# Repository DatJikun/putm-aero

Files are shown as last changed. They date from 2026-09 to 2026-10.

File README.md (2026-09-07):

# putm-aero

To jest wiki pakietu aerodynamicznego PUT Motorsport (Formula Student): ustalenia, cele i notatki ze źródeł — bez zgadywania liczb.

**Gdzie jesteśmy.** Jedziemy na aktualnym bolidzie **RWiter017** we Fluencie. Mamy mniej więcej Cx ≈ 1,23, Cz ≈ −3,68 i balans za mocno z przodu (ok. 62%). Chcemy więcej użytecznego docisku przy spokojnym oporze i balansie bliżej pół na pół, pod **Endurance** i **Autocross**. Ruchomego DRS i wentylatora spod podłogi nie robimy.

**Co dalej.** Najpierw **tylnie skrzydło** (trzy elementy na bazie 017), potem **podłoga**, a **przednie** dopiero gdy tył i podłoga ruszają balans. Decyzje na aucie tylko z Fluenta — OpenFOAM 2D jest zaparkowane i nie nadpisuje karty celów.

## Zacznij tutaj

- [Jak ulepszać pakiet](JAK-ULEPSZAC-PAKIET.md) — kolejność prac, dźwignie balansu, czego nie robić.  
- [Kierunek sezonu](SEASON-DIRECTION.md) — skrót H1 → H2 → H3 i otwarte decyzje.  
- [Karta celów](TARGETS.md) — liczby baseline, kill i zakres elementów.  
- [Kampania Fluent H1](SPEC-FLUENT-H1-RWITER017.md) — co kręcić na tylnym skrzydle na aucie.  
- [Workflow](WORKFLOW.md) — jak liczyć i jak trzymać repo, żeby decyzje były uczciwe.  
- [Mapa repo](MAPA-REPO.md) — spis folderów (dodatek; najpierw czytaj powyższe).

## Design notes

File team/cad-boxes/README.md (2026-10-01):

# Boxy aero FS 2027 (+ 2026 do porównania) — STEP do SolidWorksa

Parametryczny generator stref z T 8.2 / T 2.1.3 / T 2.1.4. Reguły i cytaty: [`sources/fs-rules-2027-t8.md`](../../sources/fs-rules-2027-t8.md), szare strefy: [`sources/rules-2027-aero-loopholes.md`](../../sources/rules-2027-aero-loopholes.md).

## Pliki (`out/`)

| Plik | Co to jest | Kiedy otwierać |
|---|---|---|
| `fs2027_dozwolone_full.step` | **tylko** przestrzeń, w której aero może być (keep-outy odjęte, zapas 10 mm) | to jest „box” do pracy |
| `fs2027_dozwolone_half_yneg.step` | to samo, połowa auta (y ≤ 0) — jak CFD | do złożenia CFD |
| `fs2027_zakazane.step` | keep-outy kół T 2.1.3 + dwa warianty T 2.1.4 | do Interference Detection |
| `fs2026_dozwolone_full.step` | boxy 2026 v1.1 | co z obecnego auta wypada w 2027 |
| `ref_opony.step` | opony z parametrów | do dopasowania w złożeniu |
| `limits.md`, `preview.png` | tabela wymiarów, widok z boku i z tyłu | szybki podgląd |

Strefy **dozwolone i zakazane są w osobnych plikach**. SolidWorks nie wczytuje kolorów z STEP-a, więc w jednym pliku nie dałoby się ich odróżnić.

Nazwy brył: `OK_*` dozwolone · `SZARA_*` przód outboard od opon (T 8.2.2 milczy, loophole B3; obcięte do +150 mm) · `KO_*` keep-out dla **każdej** części auta · `Q_*` T 2.1.4 w interpretacji „Tech ustawia dowolnie” (A: 75 mm, B: 250 mm wysokości) · `REF_*` opony.

## Układ współrzędnych

Jak w `PM09-Model-CFD.SLDASM` i w CFD: wymiary w **mm**, **x do tyłu** (0 = oś przednia), **y w bok** (0 = symetria, półauto po y < 0), **z w górę** (0 = grunt). Wstawione do złożenia auta na początek układu wskakują na miejsce (sprawdzone na zrzucie).

## Parametry (`params.toml`) i skąd są

| Parametr | Wartość | Źródło |
|---|---|---|
| Rozstaw osi | 1530 | `solving.jou` + część kolegi |
| Promień opony | 205,75 | `solving.jou` + część kolegi |
| Krawędzie przedniej opony \|y\| | 490 / 700 | część kolegi, po cofnięciu jego zapasu 10 mm (≈) |
| Krawędzie tylnej opony \|y\| | 467,3 / 662 | jw. (≈) |
| x zagłówka (HR) | 1110,75 | jw. (≈) |
| `margin` | 10 | jak u kolegi; `0` = gołe limity regulaminu |
| `width_plane_mode` | `taper` | interpretacja T 8.2.2 b1 — patrz niżej |

Wartości „≈” warto potwierdzić pomiarem w złożeniu. Po zmianie: `python3 gen_boxes.py` (wymaga `pip install cadquery matplotlib`).

## Porównanie z częścią kolegi (`ref-kolegi/REF-REGULATIONS-2027.SLDPRT`)

Wierzchołki obu modeli porównane 1:1 (z jego pliku wyciągnięta geometria Parasolid). Przy tych samych wymiarach, zapasie 10 mm i `width_plane_mode = "parallel"` modele się pokrywają, poza poniższymi różnicami:

| Miejsce | Kolega | Ten generator | Kto ma rację |
|---|---|---|---|
| Przejście przód → środek | x = −290,75 (początek keep-outu koła); między −290,75 a −205,75 box do **401,5 mm** | x = −195,75 (przód opony + zapas); przed nim max **340 mm** | **T 8.2.1 b1:** przed płaszczyzną przez przód opony < 350 mm → u kolegi pas 85 mm jest za wysoki |
| Wąski pas nad tylną oponą | \|y\| ≤ 316,2 | \|y\| ≤ 307,3 | oba legalne; u kolegi zapas tylko ~1 mm (467,3 − 150 = 317,3) |
| Dół / góra przodu | 35,5 / 340,5 | 30 / 340 | do wyjaśnienia, od czego kolega liczył (różnica 0,5–5,5 mm) |
| Wąski pas od wysokości | 421,5 (góra opony + 10) | 401,5 (góra opony − 10) | oba legalne; między 401,5 a 421,5 kolega nie ma żadnej strefy |
| Szerokość nisko za tylną osią | stałe 690 (`parallel`) | zbieżne 690 → 641 (`taper`) | zależy od interpretacji T 8.2.2 b1 → **Q&A** |
| T 2.1.4 | jeden box 510 × 85 na środku | dwa warianty „najgorszy przypadek” w pliku `zakazane` | interpretacja otwarta → **Q&A** |

## Jak sprawdzić auto w SolidWorksie

1. **Keep-out:** Tools → Evaluate → Interference Detection między częściami auta a `fs2027_zakazane.step`. Każda kolizja = problem na Tech.
2. **Envelope aero:** część aero musi się mieścić w sumie brył z `fs2027_dozwolone_*`. Szybki test: Combine → Subtract (część minus bryły `OK_`) — jeśli coś zostaje, to ten fragment wystaje.
3. Najpierw **RWiter017**: pas „góra opony – 700 mm” ma szerokość tylko do \|y\| = 307 mm.

## Uproszczenia

- Opona jako walec (bez cambera, bulge i ugięcia) — przy dużym camberze zostawcie większy zapas (T 8.2.4).
- Środek auta liczony pod **niższą** z gór opon przód/tył (niejasność C2).
- Prześwit 30 mm bez zapasu.

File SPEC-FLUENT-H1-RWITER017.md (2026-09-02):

# Kampania Fluent H1 — tylne skrzydło na RWiter017

Krótki plan Spec po zaparkowaniu 2D OpenFOAM. Liczymy **na aucie we Fluencie**, nie przenosimy Cl z 2D.

**OpenFOAM nie do auta** — porównania i kampania H1 na bolidzie tylko we **Fluencie**. 2D OpenFOAM jest **zaparkowane** (instrukcja na później: `docs/PROTOKOL-2D-OPENFOAM.md`, `SPEC-H1-2D-GATE.md`).

---

## Po co

Cofnąć balans z ok. **62%** na przód w stronę **50/50**, nie pogarszając docisku i trzymając spokojny opór. Najpierw **tylnie skrzydło** (H1), podłoga później (H2).

---

## Punkt startu (nie zmieniać)

Z `TARGETS.md` / RWiter017 @ 15 m/s, half-car, Aref **0,50 m²**, Lref **1,53 m**, moment przy **x = 0,765 m**:

- Cx = **1,229**
- Cz = **−3,682**
- Cm = **−0,429**
- balans przód ≈ **61,6%**

---

## Co kręcić (tylko RW)

Na geometrii **3-elementowej** (domyślna ścieżka):

1. Kąty elementów (zwłaszcza main / flapów) — ostrożnie, bez pchania w stall.  
2. Overlap i szczelina (gap) między elementami.  
3. Ewentualnie lokalne detale TE / endplate tylko jeśli nie mieszają setupu Fluent.

**4 elementy:** jeden case porównawczy obok zwycięskiego 3-el. — nie domyślna baza.

Nie kopiujemy Cl/Cd ani „optimum” z serii 2D OpenFOAM na ten case. 2D może najwyżej podpowiedzieć **kierunek** (np. „nie podnoś main”), gdy wróci z czystym mesh study (`SPEC-H1-2D-GATE.md` = instrukcja na później).

---

## Kill / pass (całe auto)

Case odpada albo nie idzie do CAD final, jeśli:

- |Cz| **spada poniżej 3,682** (gorzej niż baseline), albo  
- Cx **wyraźnie powyżej ~1,23** bez świadomej decyzji, albo  
- balans **nie idzie w stronę 50/50** (albo jedzie w złą stronę — jeszcze bardziej na przód).

Pass diagnostyczny: |Cz| ≥ 3,682, Cx ≲ 1,23, balans bliżej 48–52% niż 62%.

Raportuj Cx, Cz, Cm, balans % (albo Cz przód/tył) przy tym samym Aref/Lref/punkcie momentu.

---

## Kolejność

1. Baseline RWiter017 odtworzony / potwierdzony w Fluent (te same liczby).  
2. Seria 3-el.: overlap → gap → kąty (albo kąty po ustaleniu slotów — byle jeden parametr naraz).  
3. Jeden porównawczy **4-el.**  
4. Dopiero potem H2 podłoga (osobna kampania).

---

## Świadomie poza tą kampanią

- OpenFOAM half-car i 2D OF — **zaparkowane** / nie blokują Fluenta.  
- DRS ruchomy — OUT.  
- Wentylator — OUT.  
- Wąsy — TBD, nie w tej serii.

---

*Źródło prawdy liczb: `TARGETS.md`. Bramka 2D na przyszłość: `SPEC-H1-2D-GATE.md`.*

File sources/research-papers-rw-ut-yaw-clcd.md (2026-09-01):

# Przegląd literatury: tylne skrzydło (3 czy 4 elementy), podłoga w zakręcie, opublikowane liczby docisku i oporu

**Status:** Notatka badawcza do bazy źródeł, stan na 2026-09-01.  
**Język:** Polski, ton koleżeński — pełne zdania, bez telegraficznego skrótu.  
**Zakres:** Publiczne prace, tezy i strony teamów. Preferujemy materiały z EU Formula Student oraz reguł FSG dla EV; inne serie FS/FSAE oznaczamy wprost.  
**Zasada:** Każda liczba w tekście ma link, DOI albo cytat. Jeśli czegoś nie ma w źródle, piszemy **nie znaleziono**. Nic nie wymyślamy.  
**Nasz punkt wyjścia:** konfiguracja RWiter017 (Fluent, Aref zespołu):

- Cx = **1,229**
- Cz = **−3,682**
- Cm = **−0,429**
- balans ≈ **61,6%** na przód (`1/2+Cm/Cz`)

Cel zespołu to mniej więcej pół na pół. Ruchome DRS i wentylator spod podłogi są u nas wyłączone. Rozważamy czteroelementowe tylne skrzydło oraz mocniejszą podłogę.

**Powiązane notatki w bazie:**  
[staniszewski-2023-wing.md](staniszewski-2023-wing.md) · [staniszewski-2024-energy.md](staniszewski-2024-energy.md) · [naglowski-2024-package.md](naglowski-2024-package.md) · [jackson-2018-cfd-drs.md](jackson-2018-cfd-drs.md) · [research-aero-for-targets.md](research-aero-for-targets.md) · [research-balance-shift.md](research-balance-shift.md) · [research-eu-fs-ev-top-teams.md](research-eu-fs-ev-top-teams.md) · [michalecki-fan-ground-effect.md](michalecki-fan-ground-effect.md)

---

## Po ludzku — o co chodziło

Szukaliśmy **otwartych** prac o trzech rzeczach, które nas bolą. Po pierwsze: czy komuś udało się opublikować porównanie **trzech versus czterech elementów** na tylnym skrzydle razem z liczbami. Po drugie: jak **podłoga i dyfuzor** zachowują się przy kącie (skręt / wiatr boczny) oraz w zakręcie i co to robi z balansem. Po trzecie: jakie wartości **Cl, Cd i balansu** leżą w tabelach dla całych pakietów Formula Student.

Wniosek w skrócie brzmi tak. **Trzyelementowe tylne skrzydło jest dobrze udokumentowane**, w tym w naszych notatkach ze Staniszewskiego i Jacksona. **Czteroelementowe skrzydło istnieje w tezach**, ale **nie znaleźliśmy uczciwego porównania head-to-head „3 vs 4 na tym samym aucie” z różnicą współczynników docisku i oporu**. Za to **mapy podłogi przy kącie i w zakręcie** oraz kilka **pełnych pakietów z liczbami** da się zebrać i tu poniżej to robimy.

---

## 1. Tylne skrzydło: trzy czy cztery elementy?

### Co już mamy w bazie (trzy elementy)

Poniższa tabela zbiera to, co już leży w bazie wiedzy o skrzydłach trzyelementowych.

| Twierdzenie | Skąd wiemy | Pewność | Link |
|---|---|---|---|
| PUT RW w Staniszewski 2023 = **3 profile**; 2D izolowane: baseline Fz≈**−398 N**, overlap −30 mm → Fz≈**−565 N** @ 15 m/s; na pojeździe Cx≈**0,72**, Cz≈**−2,03** | tabele pracy | **wysoka** | [staniszewski-2023-wing.md](staniszewski-2023-wing.md) |
| Jackson 2018 (Huddersfield, UK FS): RW **3 el.** E423; gap/overlap wg McBeath; DRS closed CL_DF **1,15**, CD **1,21**; DRS open CL **0,26**, CD **0,79** (−**35%** siły oporu) | abstract + results | **wysoka** | [jackson-2018-cfd-drs.md](jackson-2018-cfd-drs.md); https://www.fieldsjournal.org.uk/article/414/galley/124/download/ |
| Top EU w otwartych źródłach traktują **3-el. RW jako default**; **brak** publicznych liczb „4-el. bije 3 o X%” u AMZ/Aachen/Delft | research-eu-fs-ev-top | **wysoka** (gap) | [research-eu-fs-ev-top-teams.md](research-eu-fs-ev-top-teams.md) |

Innymi słowy: nasze własne źródła i Jackson solidnie opisują układ trzech elementów. Topowe teamy europejskie w publicznych materiałach traktują trzyelementowe RW jako domyślne rozwiązanie. Nigdzie u AMZ, Aachen ani Delft nie znaleźliśmy otwartej liczby w stylu „czwarty element bije trzeci o X procent”.

### Źródła zewnętrzne o 4 elementach / multi-element (liczby tylko wtedy, gdy naprawdę są)

| Twierdzenie | Skąd wiemy | Pewność | Link |
|---|---|---|---|
| **Dynamics UPC** (Quintanas i Yani, 2023, Manresa): w sezonie dodano **czwarty flap** do RW; motywacja = więcej parametrów setupu (kąty + gurney na 3./4. foil); w konkluzji PDF: RW generuje **240 N** docisku, druga konfiguracja flapów obniża opór całego auta o **58 N**, masa RW **7 kg** | abstract + conclusion PDF (UPCommons) | **wysoka** (istnienie 4. foila + N/kg); **średnia** (warunki CFD/V nie w abstractcie — nie porównywać 1:1 z 017) | https://hdl.handle.net/2117/396194 |
| **University of Pretoria** (FSAE, nie EU): za McBeathem zrobiono RW **4-el.** (main E423 + slat + 2 flaps S1223); JavaFoil (inviscid) CL≈**5,7**; Fluent (viscous laminar) CL≈**4,2**; FW Fluent CL≈**3,6** — to **izolowane 2D skrzydło**, nie pełne auto | paper w UP repository | **wysoka** (liczby 2D); **niska** transfer na pakiet PUT | https://repository.up.ac.za/handle/2263/62356 ; bitstream https://repository.up.ac.za/bitstreams/58f0b6ab-1b15-4838-98d1-87fd075c4911/download |
| SV-JME 2016 (SAE Formula): porównanie bazy **2 flaps** vs advanced (**slat + 1 flap**, nie „3 vs 4”): DF **162,4 N → 171,6 N** (~**+6%**) przy tym samym height | DOI | **wysoka** (Δ); **niska** jako 3vs4 | https://doi.org/10.5545/sv-jme.2016.3240 |
| Fluids MDPI 2022 (FS DRS, **3 el.** main 4° / flap1 28° / flap2 60°): 3D z aktuatorami CL≈**1,160**, CD≈**0,397**; DRS → ~**−78%** CD skrzydła — **nie** 4-el. | abstract HTML (pełny HTML MDPI czasem blokowany) | **wysoka** jako 3-el. ref. | https://doi.org/10.3390/fluids7090309 |
| LUT / Metropolia HPF026 (teza, EV FS): parametric study **secondary flaps / slot gaps** + cascade na baseline RW — focus na lap/DF trade-off, **nie** jawne „3 vs 4” z tabelą ΔCl | LUTPUB abstract | **średnia** (kierunek) | https://lutpub.lut.fi/handle/10024/171732 |
| IIUM 2017 (FS downforce package): 2-el. 2D max CL≈**3,63** (L/D 21,5) lub L/D≈**54,1** przy CL≈**2,83**; gurney **0,05·c1** → **+5,8%** DF | DOI | **średnia** (2-el., nie 3vs4) | https://doi.org/10.31436/iiumej.v18i2.679 |

Co z tej tabeli wynika w praktyce. UPC naprawdę dorzuciło czwarty flap w sezonie. W konkluzji PDF podaje:

- docisk RW = **240 N**
- druga konfiguracja flapów → opór całego auta **−58 N**
- masa RW = **7 kg**

Nie mamy jednak w abstractcie pełnych warunków CFD ani prędkości, więc tych niutonów nie wolno porównywać jeden do jednego z naszym `RW_iter017`. Pretoria opisuje czteroelementowe RW według McBeatha, ale to izolowane skrzydło dwuwymiarowe. SV-JME, Fluids MDPI, LUT i IIUM pokazują multi-element, ale żadne z nich nie jest czystym head-to-head „trzy versus cztery elementy na tym samym aucie”.

### Werdykt tematu 1

**Opublikowanego porównania head-to-head trzech versus czterech elementów na tym samym tylnym skrzydle, z różnicą współczynników docisku i oporu/Fz, nie znaleziono.**

Czteroelementowe RW **nie jest „rzadkie jak yeti”** — UPC i Pretoria to robią albo opisują. Nie ma jednak gotowej tabeli w stylu „ile procent zysku daje czwarty element”, którą można wkleić do Specu.

Geometrię startową nadal bierzemy z McBeatha (przez Jacksona):

- gap = **1–4%c**
- overlap = **1–6%c**
- ostatnie flapy wysoko, mniej więcej **25–70°**, tuż przed stalem

---

## 2. Podłoga i dyfuzor — balans przy kącie i w manewrach

### Nasze prace PUT (już w bazie)

| Twierdzenie | Skąd wiemy | Pewność | Link |
|---|---|---|---|
| UT&SW **silnie wrażliwe** na kierunek napływu; przy δ≠0 spadek sił z podłogi; FW/RW „płaskie”; nie ekstrapolować zakrętu z δ=0 | Staniszewski 2024 s. 55–56 | **wysoka** | [staniszewski-2024-energy.md](staniszewski-2024-energy.md) |
| Pełny pakiet (z UT) vs FW&RW: wyższe \|Cz\| w całym δ; Cx krzywe przecinają się ~**10°**; proxy energii toru **F2/F1 = 0,973 → −2,7%** mimo **+~10 kg** UT | wzór (20) + s. 67–68 | **wysoka** (proxy F_ham); **średnia** jako Wh | [staniszewski-2024-energy.md](staniszewski-2024-energy.md) |
| Nagłowski baseline @15 m/s: Fz_ut ≈ **−202 N** z Fz_all ≈ **−561 N** (~**36%**); balans **60,3%** przód | Tab. 5.2–5.3 | **wysoka** (ich model ≠ 017) | [naglowski-2024-package.md](naglowski-2024-package.md) |

Z naszych własnych prac wynika więc, że undertray i sidewalls mocno reagują na kierunek napływu. Przy δ różnym od zera siły z podłogi spadają, a skrzydła zachowują się względnie „płasko”. Nie wolno ekstrapolować zachowania w zakręcie z samego δ = 0. Pełny pakiet z UT daje wyższe \|Cz\| w całym zakresie δ. Z Staniszewskiego 2024:

- krzywe Cx przecinają się około **10°**
- proxy energii toru: **F2/F1 = 0,973** → **−2,7%**
- masa UT ≈ **+10 kg**

U Nagłowskiego (inny model niż `RW_iter017`):

- udział UT ≈ **36%** całego Fz
- balans = **60,3%** na przód

### Chalmers CFS 2021 — tabele: jazda na wprost, zakręt, hamowanie

Źródło: De Wilde et al., *Development and performance evaluation of undertray diffusers during racing manuevers*, Chalmers BSc 2021.  
PDF: https://odr.chalmers.se/bitstreams/2e9b2842-d1d0-4c5a-aa01-a13458f7ddaf/download  

Scenariusz zakrętu w tej pracy (Tab. 3.4):

- R ≈ **12,5 m**
- V ≈ **40 km/h**
- poślizg nadwozia = **3,5°**
- roll = **0,7°**
- kąt skrętu kół ≈ **7,2–7,4°**

Uwaga metrologiczna: w tej pracy CL oznacza **współczynnik docisku** (ujemny lift zapisany jako dodatni CL), a aero balance jest podany **w stronę tyłu**.

**Tabela 4.1 — mały dyfuzor (0 mm start), komponenty:**

| Scenariusz | CD | CL | CL M&D | CL FW | CL RW | Aero balance (tył) |
|---|---:|---:|---:|---:|---:|---:|
| Na wprost | **1,433** | **3,612** | 0,435 | 1,352 | 1,032 | **50,06%** |
| Zakręt | **1,302** | **3,544** | 0,436 | 1,325 | 0,983 | **49,90%** |
| Hamowanie (pitch ~1°) | **1,355** | **2,799** | 0,336 | 0,773 | 1,013 | **67,17%** |

**Kąt ekspansji (start 500 mm) — Tab. 4.3 (fragment):**

| Design | Scenariusz | CD | CL | CL M&D | Balance (tył) |
|---|---|---:|---:|---:|---:|
| **13°** | Na wprost | 1,419 | **3,729** | 0,515 | 49,68% |
| **13°** | Zakręt | 1,380 | **3,603** | 0,470 | 49,38% |
| 15° | Na wprost | 1,424 | 3,640 | 0,483 | 50,36% |
| 19° | Na wprost | 1,402 | 3,663 | 0,497 | 49,35% |

Wniosek autorów brzmi następująco. Kąt **13°** wybrano za odporność w manewrach, a nie dlatego, że zawsze daje maksymalny CL w jednym punkcie. Strakes i side floors dalej pomagają. Typowa literatura startuje od około **15°**; zbyt stromy dyfuzor prowadzi do separacji.

| Twierdzenie | Skąd wiemy | Pewność | Link |
|---|---|---|---|
| Cornering przy R=12,5 m prawie nie zabija CL całego auta vs straight (**3,544 vs 3,612**), ale **braking pitch** zabija FW (−**43%** CL_FW) i cofa balans mocno do tyłu (**67%** tył) | Tab. 4.1 | **wysoka** | Chalmers PDF: https://odr.chalmers.se/bitstreams/2e9b2842-d1d0-4c5a-aa01-a13458f7ddaf/download |
| 13° ekspansji: najwyższy CL w badanych kątach + lepsza kontrola wirów vs 15–19° | Tab. 4.3 + dyskusja | **wysoka** na CFS; **średnia** transfer | Chalmers PDF: https://odr.chalmers.se/bitstreams/2e9b2842-d1d0-4c5a-aa01-a13458f7ddaf/download |

### Oregon State (FSAE undertray) — yaw + roll

| Twierdzenie | Skąd wiemy | Pewność | Link |
|---|---|---|---|
| UT + auto w CFD: nominal ~**50 lb** DF; przy **5° yaw** (bez roll) DF ↑ do **62 lb**; **1° roll** przy yaw obniża DF o **~6%** | § Results | **wysoka** (lb, ich model) | https://ir.library.oregonstate.edu/downloads/7h149t91w |
| Lokalizacja wejścia dyfuzora przesuwa peak podciśnienia → dźwignia **balansu** UT | literatura + design discussion | **wysoka** (kierunek) | https://ir.library.oregonstate.edu/downloads/7h149t91w |

U Oregon State (ich model, lb):

- nominalny DF (UT + auto) ≈ **50 lb**
- przy yaw **5°** (bez roll) DF → **62 lb**
- yaw **5°** + roll **1°** → DF **−~6%**

Lokalizacja wejścia dyfuzora przesuwa peak podciśnienia i działa jak dźwignia balansu undertray.

### FST Lisboa / Técnico — aeromap (EU EV)

| Twierdzenie | Skąd wiemy | Pewność | Link |
|---|---|---|---|
| Na FST10e **yaw** najbardziej wrażliwy: **~16%** zmiany docisku w badanym zakresie; **roll ~9%** DF i **~12%** przesunięcia CoP; ride height **~10%** CD·A i **~20%** −CL·A między peakami; mapa **>100** punktów | abstract tezy | **wysoka** na FST10e; **średnia** transfer | https://scholar.tecnico.ulisboa.pt/records/WjT08GaGU4ee77V1ZI_WgpbeDe_scfAseZd-?lang=en |

Na FST10e yaw okazał się najbardziej wrażliwym kątem. Z abstractu tezy:

- yaw → ~**16%** zmiany docisku w badanym zakresie
- roll → ~**9%** DF i ~**12%** przesunięcia CoP
- ride height → ~**10%** CD·A oraz ~**20%** −CL·A między peakami
- mapa > **100** punktów

### Kirchberger / TU Wien EDGE 14 (EU EV)

| Twierdzenie | Skąd wiemy | Pewność | Link |
|---|---|---|---|
| UT generuje **~40%** docisku EDGE 14 — „most important” device w ich narracji | § Validation | **wysoka** (ich auto) | https://doi.org/10.34726/hss.2023.115880 ; PDF https://repositum.tuwien.at/bitstream/20.500.12708/188917/1/Kirchberger%20Michael%20-%202023%20-%20CFD%20Simulation%20and%20Validation%20of%20a%20Formula%20Student..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 |
| Mesh study (half-car): CLA stagnuje ~**5,1–5,2 m²**, CDA ~**1,7 m²** na najdrobniejszych siatkach; typowy design mesh base 33 mm: CLA **4,72**, CDA **1,57**; converged run CLA **−4,66**, CDA **1,51–1,57** | Tab. 2.1–2.3 | **wysoka** (CLA/CDA = ×A) | https://doi.org/10.34726/hss.2023.115880 ; PDF https://repositum.tuwien.at/bitstream/20.500.12708/188917/1/Kirchberger%20Michael%20-%202023%20-%20CFD%20Simulation%20and%20Validation%20of%20a%20Formula%20Student..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 |

U Kirchbergera undertray generuje około **40%** docisku EDGE 14 i w ich narracji jest „najważniejszym” urządzeniem. Mesh study half-car:

- najdrobniejsze siatki: CLA ≈ **5,1–5,2 m²**, CDA ≈ **1,7 m²**
- typowy design mesh (baza 33 mm): CLA = **4,72**, CDA = **1,57**
- zbieżny run: CLA = **−4,66**, CDA = **1,51–1,57**

### Inne (modelowanie cornering)

| Twierdzenie | Skąd wiemy | Pewność | Link |
|---|---|---|---|
| NTNU (Revolve context): stały yaw ≠ prawdziwy cornering (rotating flow) — efekty momentów bywają **przeciwne** do fixed-yaw | thesis abstract | **wysoka** (metoda) | http://hdl.handle.net/11250/2433712 |
| ASME JEF (Balasko/Zonta, 2025): w corneringu CLA spada **>20%** (mocniej przy małych R); możliwy **rearward** shift balansu / understeer z FW stall | abstract / guest PDF snippet | **med–high** (pełny PDF paywall) | https://doi.org/10.1115/1.4069995 |
| SAE 2017-01-5016 (under tray diffuser FS): best CFD case inlet **3°** / outlet **10°** / GC **30 mm** (L/D); słaby: 5°/16°/50 mm — **paywall abstract**, liczby z abstractu | DOI | **średnia** | https://doi.org/10.4271/2017-01-5016 |

NTNU ostrzega, że stały yaw to nie to samo co prawdziwy cornering z rotating flow — efekty momentów bywają nawet **przeciwne** do fixed-yaw. ASME JEF 2025 raportuje spadek CLA o **więcej niż 20%** w corneringu, mocniejszy przy małych promieniach, oraz możliwy rearward shift balansu albo understeer ze stallu przedniego skrzydła. SAE 2017-01-5016 (liczby z abstractu, pełny tekst za paywallem):

- najlepszy CFD: inlet **3°** / outlet **10°** / GC **30 mm**
- słaby przypadek: **5°** / **16°** / **50 mm**

### Werdykt tematu 2

Mamy **konkretne mapy i tabele** z Chalmers, Oregon, FST Lisboa oraz Staniszewskiego 2024. Wspólny obraz jest jasny. **Undertray to duży udział docisku i największa wrażliwość na yaw oraz attitude.** Braking pitch potrafi bardziej rozwalić balans niż typowy zakręt Formula Student. **Nie wolno zamrażać undertray na samym δ = 0.**

---

## 3. Opublikowane liczby docisku, oporu i balansu dla całych pakietów

> **Uwaga metrologiczna:** Cx/Cz PUT (Fluent, Aref zespołu) nie są tym samym co CLA/CDA w metrach kwadratowych, ani tym samym co Cl/Cd ze stron teamów (często bez Aref albo z DRS). **Nie wolno mieszać tych wielkości w jednym wykresie bez wspólnego Aref.**

| Źródło / kontekst | Cl / Cz / CLA | Cd / Cx / CDA | Balans | Warunki | Link | Conf. |
|---|---|---|---|---|---|---|
| **PUT RWiter017** (kotwica) | Cz **−3,682** | Cx **1,229** | **≈61,6%** przód (`1/2+Cm/Cz`) | 15 m/s, half-car | [research-balance-shift.md](research-balance-shift.md) | **wysoka** |
| **Nagłowski 2024** (PUT, inny model) | Cz **−4,071** | Cx **1,453** | **60,3%** przód | 15 m/s | [naglowski-2024-package.md](naglowski-2024-package.md) | **wysoka** |
| **Staniszewski 2023** 3D pojazd | Cz **−2,036** | Cx **0,726** | nie podano | 15 m/s | [staniszewski-2023-wing.md](staniszewski-2023-wing.md) | **wysoka** |
| **Jackson 2018** + RW DRS closed | CL_DF **1,15** | CD **1,21** | nie (DF głównie tył) | 26,8 m/s; A=1,18 m² | Jackson / Fields | **wysoka** |
| **Jackson** DRS open | CL_DF **0,26** | CD **0,79** | — | A=0,99 m² | [jackson-2018-cfd-drs.md](jackson-2018-cfd-drs.md); https://www.fieldsjournal.org.uk/article/414/galley/124/download/ | **wysoka** |
| **Chalmers CFS** small diffuser straight | CL **3,612** | CD **1,433** | **~50%** tył | 40 km/h | Chalmers PDF Tab. 4.1 | **wysoka** |
| **Chalmers** 13° diffuser straight | CL **3,729** | CD **1,419** | 49,68% tył | 40 km/h | Tab. 4.3 | **wysoka** |
| **Kirchberger EDGE14** | CLA **≈4,66…5,2 m²** | CDA **≈1,51…1,72 m²** | — | half-car StarCCM+; mesh study | reposiTUm DOI | **wysoka** |
| **Rennstall Esslingen** Stallardo25 | CL\*A **4,9** | CD\*A **1,65** | nie znaleziono | cornering **50 km/h** (strona teamu) | https://www.rennstall-esslingen.com/stallardo25 | **wysoka** |
| **PoliTO SC24** Andromeda (EV) | ClA ≈ **4,75** | CdA ≈ **1,45** | nie znaleziono | CFD + WT Dec 2023 (teza Cravero) | https://webthesis.biblio.polito.it/35911/1/tesi.pdf | **wysoka** |
| **eForce CTU.25** (EV, **z DRS**) | Cl **−5,9** | Cd **2,02** | masa 52/48 (nie aero) | DF **320 kg @ 100 km/h**; DRS −**30%** drag | https://eforce.cvut.cz/ctu-25-en/ | **wysoka** (strona); Aref **nie podany** |
| **Wordley & Saunders / Monash 2005** (FSAE WT) | — | CD **0,83** (baseline cytowany przez Jackson) | — | WT | SAE 2006-01-0806/0808 (abstract) | **średnia** (paywall pełny tekst) |
| **AMZ / Aachen / Delft / Tallinn / Joanneum 2024–25** | **nie znaleziono** publicznych Cl/Cd pakietu konkursowego | — | **nie znaleziono** % aero | — | [research-eu-fs-ev-top-teams.md](research-eu-fs-ev-top-teams.md) | **wysoka** (gap) |
| Maryland TR25 active aero (FSAE IC, **nie** EU EV) | CD **1,44 → 0,73** (−49%); CoP **78%→20%** front DF | — | active | AIAA 2026 abstract | https://doi.org/10.2514/6.2026-110799 | **średnia** (inna klasa; DRS-like) |

### MDPI CarMaker Part 2 (ART_X) — mapa Cd versus crosswind + DRS

Źródło: https://www.mdpi.com/2673-4591/79/1/77 (2024) — DRS off/on, kąty ±0…20°.

| Crosswind [°] | CD DRS off | CD DRS on |
|---:|---:|---:|
| 0 | **1,711** | **1,314** (~−25%) |
| ±5 | 1,528 | 1,173 |
| ±10 | 1,367 | 1,045 |
| ±20 | 1,190 | 0,913 |

Ta tabela jest przydatna jako **wzór mapy yaw**, a nie jako target PUT — u nas DRS jest OUT.

---

## Czego uczciwie nie znaleziono

Poniżej wypisujemy uczciwie to, czego nie znaleźliśmy albo czego nie wolno przeskalować na nasz pakiet.

1. **Brak publikacji Δ(3-el → 4-el) na tym samym RW** z Cl/Cd/Fz i wspólnym Aref. Hipoteza H1 zostaje więc **hipotezą CAD/CFD**, a nie twierdzeniem typu „literatura mówi +X%”.
2. Topowe teamy EU (AMZ, Aachen, Delft, Tallinn, Joanneum) **nie publikują** Cl/Cd ani balansu konkursowego. Mamy tylko procesy oraz rzadkie CLA/CDA (Esslingen, Kirchberger, PoliTO, CTU).
3. W Staniszewskim 2024 **konkretne Cx(δ)/Cz(δ) są tylko na wykresach**. W plain text brak tabeli punktowej — nie OCR-owano wykresów.
4. ASME cornering 2025: pełny PDF stoi za paywallem. Mamy snippet o spadku CLA **>20%**, ale nie pełną tabelę.
5. U Quintanasa (conclusion PDF, UPCommons):

   - docisk RW = **240 N**
   - Δopór auta = **58 N**
   - masa RW = **7 kg**

   **Prędkość, Aref oraz to, czy pomiar dotyczy izolowanego RW czy full-car, nie zostały wyciągnięte w tej sesji z pełnego tekstu.** Nie wolno więc skalować tych wartości na `RW_iter017`.
6. CTU.25 podaje Cl/Cd **z DRS w pakiecie**. U nas DRS jest OUT. Traktujemy te liczby jako górny rząd wielkości DF, a nie jako setup do kopiowania.
7. Fan oraz powered ground effect leżą poza zakresem Specu (OUT). Szczegóły są w notatce Michalecki w KB.

---

## Co z tego wynika dla naszego zespołu

**H1 — kandydat na RW 4-elementowe.** Literatura **nie da Ci gotowego ΔCl**. Daje motywację: UPC podkreśla więcej parametrów setupu oraz ekspozycję ostatniego flapu; Pretoria i McBeath pokazują, że układ 4-elementowy jest osiągalny w boxie FSAE. Ostrzeżenia: Staniszewski przypomina, że 2D nie równa się 3D coupling; UPC waży RW około **7 kg**; trzeba pilnować sztywności według T8.3. Gate dla nas — tabela na pakiecie 017 z Δbalans / ΔCx / ΔCz względem baseline 3-elementowego:

- Cx ≲ **1,23**
- \|Cz\| ≥ **3,682**

**H2 — undertray.** To jest **najmocniej udokumentowana** dźwignia w tym researchu. Z paperów:

- Chalmers: kąt **13°** + strakes + manewry
- Oregon: yaw **5°**; roll przy yaw → DF **−~6%**
- FST Lisboa: ~**16%** zmiany DF od yaw
- Staniszewski 2024: mapy δ; proxy energii **−2,7%**
- Kirchberger: UT ≈ **40%** DF

Szukamy więc **tylniejszego** docisku dyfuzora **bez** dokręcania nosa przedniego skrzydła. Bramka decyzyjna: mapa Cx/Cz versus δ (plus roll/ride height, jeśli starczy budżetu) przed zamrożeniem geometrii.

**Balans 61,6% → około 50%.** Żaden top team nie opublikował instrukcji „róbcie 50% tak jak my”. Chalmers celuje w okolice **50/50** (nawet z narracją rear-biased). Nasze dźwignie to **H1 RW + H2 UT**, potem ewentualnie odciążenie FW (H3), a wąsy zostają TBD (H4). Nie dokręcamy samego przedniego skrzydła.

**DRS OUT / fan OUT.** Jackson oraz MDPI/CTU pokazują, że otwarty DRS zjada docisk. U nas w 019/020:

- \|Cz\| ≈ **3,01**
- to poniżej kotwicy **3,682**

Fan jest opisany u Michaleckiego. Nie projektujemy peak-DF przez te ścieżki.

**Kolejność pracy:** H1 → H2 → (H3) → H4. Zawsze na **pełnym pakiecie** oraz przynajmniej z **mapą versus δ**.

---

## Lista źródeł

| # | Źródło | Temat | Liczby? |
|---|---|---|---|
| 1 | Staniszewski 2023 (PUT) | RW 3-el. | tak |
| 2 | Staniszewski 2024 (PUT) | yaw/δ, UT | tak (proxy) |
| 3 | Nagłowski 2024 (PUT) | pakiet Fz/balans | tak |
| 4 | Jackson 2018 | RW 3-el. + DRS | tak |
| 5 | Quintanas UPC 2023 | RW **4-el.** | tak (N, kg) |
| 6 | Pretoria FSAE paper | RW 4-el. 2D CL | tak |
| 7 | Chalmers undertray 2021 | UT manewry | tak (tabele) |
| 8 | Oregon State undertray | yaw/roll UT | tak |
| 9 | FST Lisboa aeromap abstract | yaw sensitivity | tak (%) |
| 10 | Kirchberger 2023 EDGE14 | CLA/CDA, UT% | tak |
| 11 | PoliTO Cravero 2025 | ClA/CdA SC24 | tak |
| 12 | eForce CTU.25 page | Cl/Cd + DF kg | tak |
| 13 | Esslingen Stallardo25 | CL\*A/CD\*A | tak |
| 14 | MDPI Eng. Proc. 79/77 | Cd vs yaw + DRS | tak |
| 15 | SV-JME 2016 | multi-el. ΔDF | tak |
| 16 | Fluids 2022 DRS 3-el. | CL/CD skrzydła | tak |
| 17 | IIUM 2017 | 2-el. CL | tak |
| 18 | NTNU cornering CFD thesis | metoda yaw vs rotate | qualitative+ |
| 19 | ASME JEF 2025 cornering | CLA −>20% | tak (snippet) |
| 20 | LUTPUB Metropolia RW study | parametric flaps | abstract |
| 21 | research-eu-fs-ev-top (KB) | top EU gaps | meta |

**Liczba źródeł z liczbami (Cl/Cd/Fz/CLA/%/N):** **≥ 16** (wiersze 1–16 powyżej plus snippet ASME).  
**Źródła bez head-to-head 3 vs 4:** ta luka jest jawna i pozostaje otwarta.

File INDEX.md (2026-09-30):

# FS Aero — baza wiedzy (indeks)

Stan na 2026-09-01 (aktualizacje nocne do 2026-09-02).
Tu trzymamy źródła i zamrożone ustalenia zespołu.
Liczby tylko ze źródeł — bez zgadywania.

---

## Nawigacja

- [WORKFLOW.md](WORKFLOW.md) — co poprawić w workflow CFD i repo
- [JAK-ULEPSZAC-PAKIET.md](JAK-ULEPSZAC-PAKIET.md) — jak ulepszać pakiet (wiki)
- [MAPA-REPO.md](MAPA-REPO.md) — mapa repozytorium (co w każdym folderze, czego gdzie szukać)

## Ustalenia zamrożone (zespół)

**Punkt odniesienia (baseline):** `RW_iter017` to **aktualny bolid** po zawodach.

- Osoba w arkuszu: Michał Narożny, status Done, data 27.12.2025.
- Cx = **1,229**
- Cz = **−3,682**
- Cm = **−0,429**
- efektywność ≈ **2,996**
- Źródło: [sources/team-rwiter017-baseline.md](sources/team-rwiter017-baseline.md) oraz CSV `team/rw-iters-2025-2026.csv`.
- Wariant `RW_iter017.2` służy tylko do kontroli rozbieżności skryptu Fluent. **Nie** zamienia kotwicy.
- `Baseline002` to historyczny miks (FWiter011 + RWiter017 + UTiter002). To **nie** jest kotwica.

**Cel projektowy (lead):** jak największy docisk przy balansie około **50/50** (roboczo **48–52%** na przód).
Przy tym samym docisku nie pogarszamy oporu względem baseline (orientacyjnie Cx ≲ **1,23**).
Prędkość odniesienia w pracach PUT i w setupie CFD: **15 m/s**.

**Zakres elementów (na start):**

- Skrzydło tylne, przednie, podłoga i sekcje boczne — **wchodzą**.
- Tylne skrzydło: rozważamy **4 elementy** jako kandydata względem obecnych 3.
- Wąsy (profil typu S1223) — **jeszcze nie wiadomo**; dobór profilu dopiero pod miejsce na aucie.
- Wentylator spod podłogi — **nie**.
- DRS ruchomy — **nie**; ewentualnie tylko układ **pasywny** (jak testy 019/020), poza ścieżką peak-docisku.
- Model turbulencji Fluent: **Realizable k-ε + Enhanced Wall Treatment**.
  OpenFOAM: to samo albo wall functions przy y+ > 30 (maszyna 16 GB).

**Priorytet eventów:** Endurance i Autocross.
Cel: maksymalny docisk przy możliwie niskim oporze.
Balans: z ok. **61,6%** na przód w stronę ok. **50/50** (ok. **12 punktów procentowych**).

**Potwierdzone:** wiersz `Baseline_1` z arkusza podłogi **nie jest** tym samym bolidem co `RW_iter017`.
RWiter017 = aktualny bolid po zawodach.
Liczb balansu ok. 69% z Baseline_1 nie używamy jako startu.

**Balans RWiter017:** ≈ **61,6%** na przód (z Cm/Cz arkusza; decyzja: „jak w arkuszu”).
Do ok. 50/50 brakuje ok. **12 pp** — cofamy docisk (tylnie skrzydło / podłoga), nie dokręcamy samego przodu.
Postprocessing z OneDrive to JPG bez CSV sił, więc kotwica z arkusza zostaje.

**Aref:**

- half-car ≈ **0,50 m²** (w simach bywa 0,49–0,51)
- pełny bolid ≈ **1,0 m²**

**Otwarte:**

- masa bolidu i budżet energii,
- wąsy — ostateczny dobór profilu.

Łańcuch iteracji przedniego skrzydła (`team/fw-iters-2025-2026.csv`) to kontekst rozwoju FW.
To **nie** jest baseline całego bolidu.

---

## Literatura (prace dyplomowe / paper)

| # | Plik | Krótko |
|---|---|---|
| 1 | [sources/staniszewski-2023-wing.md](sources/staniszewski-2023-wing.md) | Staniszewski 2023 — optymalizacja 3-elementowego skrzydła tylnego (2D/3D, 15 m/s). Na pojeździe Cx/Cz ≈ 0,72 / −2,03 (inny pakiet niż dzisiejszy baseline). |
| 2 | [sources/staniszewski-2024-energy.md](sources/staniszewski-2024-energy.md) | Staniszewski 2024 — mapy Cx/Cz vs kąt skrętu i proxy energii; podłoga pomaga mimo +~10 kg. |
| 3 | [sources/naglowski-2024-package.md](sources/naglowski-2024-package.md) | Nagłowski 2024 — wąsy S1223; baza Cz=−4,071 / Cx=1,453 / balans ~60% przód @15 m/s (kotwica literaturowa, nie nasz hard target). |
| 4 | [sources/michalecki-fan-ground-effect.md](sources/michalecki-fan-ground-effect.md) | Michalecki — wentylator pod podłogą na PM08 nie bije bazy; stąd fan OUT. |
| 5 | [sources/jackson-2018-cfd-drs.md](sources/jackson-2018-cfd-drs.md) | Jackson 2018 — DRS na RW (literatura zewnętrzna). |
| 6 | [sources/strojny-2015-rp.md](sources/strojny-2015-rp.md) | Strojny 2015 — druk 3D w procesie budowy; bez liczb aero. |

Indeksy cząstkowe: [index-batch-a.md](index-batch-a.md), [index-batch-b.md](index-batch-b.md).

---

## Dane zespołu (CSV)

| Plik | Co to jest |
|---|---|
| [sources/team-rwiter017-baseline.md](sources/team-rwiter017-baseline.md) | Claim baseline `RW_iter017` oraz uwagi o balansie |
| [team/rw-iters-2025-2026.csv](team/rw-iters-2025-2026.csv) | Arkusz iteracji skrzydła tylnego |
| [team/ut-iters-with-balance-2026.csv](team/ut-iters-with-balance-2026.csv) | Arkusz podłogi z kolumną balansu (`Baseline_1` ≈ 69% przód) |
| [team/fw-iters-2025-2026.csv](team/fw-iters-2025-2026.csv) | Arkusz iteracji skrzydła przedniego (kontekst) |

## Research (robocze)

| Plik | Opis |
|---|---|
| [sources/research-balance-shift.md](sources/research-balance-shift.md) | Cofanie balansu ~61,6% → 50/50; shortlista H1–H5 |
| [sources/research-aero-for-targets.md](sources/research-aero-for-targets.md) | Rady aero pod max docisk + niski opór + Endurance/Autocross (H1–H4) |
| [sources/research-endurance-energy-aero-tradeoffs.md](sources/research-endurance-energy-aero-tradeoffs.md) | Endurance/Efficiency: trade-offy DF–drag–energia–balans (Staniszewski 2024 + EU); kiedy brać Cx za Cz |
| [sources/research-overnight-rw-multi-element.md](sources/research-overnight-rw-multi-element.md) | Noc: multi-element RW 3 vs 4, kąty/gap/overlap, DRS pasywny vs aktywny (EU FS) |
| [sources/research-overnight-ut-yaw-balance.md](sources/research-overnight-ut-yaw-balance.md) | Noc: podłoga/dyfuzor → balans + yaw; Staniszewski 2024 + Chalmers/OSU/Jowsey |
| [sources/research-papers-rw-ut-yaw-clcd.md](sources/research-papers-rw-ut-yaw-clcd.md) | Zbiorcza notatka paperów: 3 vs 4 el. RW, UT+yaw, opublikowane Cl/Cd/balans |
| [OVERNIGHT-BRIEF.md](OVERNIGHT-BRIEF.md) | Brief na jedną stronę (rano): co znaleziono, luki, PDF do dropu |
| [sources/research-balance-levers-h1-h5.md](sources/research-balance-levers-h1-h5.md) | Szczegóły dźwigni H1–H5 (mechanizm, ryzyka, kryteria zabicia ścieżki) |
| [sources/research-fs-teams-practice.md](sources/research-fs-teams-practice.md) | Praktyka innych teamów FS (FW/RW/UT, Cl/Cd/balans, Endurance vs Autocross) |
| [sources/research-amz-berlin-snails-aero.md](sources/research-amz-berlin-snails-aero.md) | AMZ / FaSTTUBe (Berlin) / Running Snail — narzędzia, walidacja, publiczne ΔDF; absolutne Cl/Cd nie znalezione |
| [sources/research-overnight-h3-fw-unload-rw-gaps.md](sources/research-overnight-h3-fw-unload-rw-gaps.md) | Noc 2: H3 odciążenie FW + reguły gap/overlap/AOA na RW; checklist pod serię CFD |
| [sources/checklist-h1-2d-rw-gap-aoa.md](sources/checklist-h1-2d-rw-gap-aoa.md) | Checklist H1: seria 2D RW — gap/overlap/AOA (bez nowych Cl/Cd do TARGETS) |
| [sources/checklist-h1-fluent-rw.md](sources/checklist-h1-fluent-rw.md) | Checklist H1 pod Fluent: kąty→overlap→gap + kill stall (OF 2D stop) |
| [sources/research-h1-overlap-gap-deep-dive.md](sources/research-h1-overlap-gap-deep-dive.md) | H1 pogłębienie: overlap/gap/AOA po bramce medium+; kill criteria; bez TARGETS |
| [sources/sanity-cfd1-2d-rw-vs-lit.md](sources/sanity-cfd1-2d-rw-vs-lit.md) | Sanity-check baseline 2D CFD#1 vs Staniszewski/Jackson/McBeath (rząd wielkości; bez TARGETS) |
| [sources/research-h2-undertray-balance-levers.md](sources/research-h2-undertray-balance-levers.md) | H2 podłoga: dźwignie balansu tył, ride height, yaw, checklista pomiarów CFD |
| [sources/research-h2-strakes-yaw-rideheight.md](sources/research-h2-strakes-yaw-rideheight.md) | H2 pogłębienie: strakes + yaw + ride height (bez TARGETS) |
| [sources/research-season-geometry-profiles.md](sources/research-season-geometry-profiles.md) | Kandydaci profili/geometrii sezonu: RW 3-el., FW, UT (~13°), wąsy — bez TARGETS |
| [sources/research-rw-3vs4-elements-teams.md](sources/research-rw-3vs4-elements-teams.md) | 3 vs 4 el. RW: papery/top teamy; bez head-to-head ΔCl na kartę |
| [sources/research-h3-fw-unload-for-balance.md](sources/research-h3-fw-unload-for-balance.md) | H3: kiedy odciążać FW pod balans (po H1+H2); siły z literatury; bez TARGETS |
| [sources/research-eu-fs-ev-top-teams.md](sources/research-eu-fs-ev-top-teams.md) | Przegląd topowych teamów EU FS EV pod pakiet aero PUT |
| [sources/research-aero-dev-tooling.md](sources/research-aero-dev-tooling.md) | Jak teamy EU FS organizują rozwój aero: tooling, workflow i śledzenie iteracji CFD |
| [sources/research-rw-endplate-packaging.md](sources/research-rw-endplate-packaging.md) | Packaging endplate RW: T8 (&lt;1,1 m, inboard, setback 250 mm); 800×500=OF 2D nie T8; Jackson 1200 mm ostrzeżenie; H1 freeze endplate → 1–2 tipy; bez Cl→TARGETS |

## Regulamin

| Plik | Opis |
|---|---|
| [sources/fs-rules-2027-t8.md](sources/fs-rules-2027-t8.md) | **2027 (wyciąg aero):** diff vs 2026 + cytaty T8 / T2.1.3–4; RW 700–1100 mm na pełną szerokość, FW <350 mm, środek < góra opon |
| [sources/rules-2027-aero-loopholes.md](sources/rules-2027-aero-loopholes.md) | **2027:** szare strefy / dźwignie w nowym envelope + ryzyko Scrutineering + pytania do Q&A |
| [team/rules-2027-aero-extract.pdf](team/rules-2027-aero-extract.pdf) | Wyciąg aero FS Rules 2027 (nieoficjalny, bez rysunków) + dump `team/rules-2027-aero-extract.txt` |
| [team/cad-boxes/](team/cad-boxes/README.md) | Boxy aero 2027 i 2026 jako STEP (SolidWorks) + generator; rozstaw kół / szer. opon / x HR = placeholdery |
| [sources/fs-rules-2026-t8.md](sources/fs-rules-2026-t8.md) | Claims + cytaty T8 / T2.2 / T11.11 z FS Rules **2026 v1.1** (sezon poprzedni) |
| [sources/rules-aero-boxes-loopholes.md](sources/rules-aero-boxes-loopholes.md) | Brief Aero Pack: boxy, DRS/fan, luki i ryzyko Scrutineering (**2026**) |
| [team/rules-current.pdf](team/rules-current.pdf) | PDF źródłowy |
| [sources/claims-from-eu-fs-ev-top.md](sources/claims-from-eu-fs-ev-top.md) | Claims do założeń z notatki EU EV |

- [SPEC-MORNING.md](SPEC-MORNING.md) — one-pager Spec na rano
- [SPEC-FROM-OVERNIGHT.md](SPEC-FROM-OVERNIGHT.md) — co nocny research zmienia w celach
- [TARGETS.md](TARGETS.md) — pełna karta celów

- [SPEC-FLUENT-H1-RWITER017.md](SPEC-FLUENT-H1-RWITER017.md) — kampania Fluent H1 na aucie

- [docs/PROTOKOL-2D-OPENFOAM.md](docs/PROTOKOL-2D-OPENFOAM.md) — protokół 2D OF (**zaparkowane**); bramka SPEC-H1-2D-GATE

- [SEASON-DIRECTION.md](SEASON-DIRECTION.md) — podsumowanie + kierunek sezonu (H1→H2→H3)

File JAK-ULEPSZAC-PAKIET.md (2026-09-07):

# Jak ulepszać pakiet aerodynamiczny

To nie jest katalog plików. To kolejność pracy: **co ruszać, w jakiej kolejności i po co**, żeby dojść od dzisiejszego bolidu do lepszego pakietu pod Endurance i Autocross.

**Liczby z karty celów** ([TARGETS.md](TARGETS.md)) to nasze targety.  
**Liczby z paperów** poniżej to tylko cytaty / kierunek — **nie** nowe cele Cx/Cz.

---

## Gdzie jesteśmy

Jedziemy na **RWiter017** we Fluencie (15 m/s, half-car). Dziś mamy mniej więcej:

- opór Cx ≈ **1,23**
- docisk Cz ≈ **−3,68**
- balans na przód ok. **62%** — za mocno z przodu

Chcemy **więcej użytecznego docisku** przy możliwie małym oporze i balansie bliżej **pół na pół** (ok. 50/50). Brakuje nam ok. **dwunastu punktów procentowych** w tył — czyli trzeba **cofnąć docisk** (tylnie skrzydło i podłoga), a nie dokręcać samego przedniego na ślepo.

Szerszy obraz sezonu: [SEASON-DIRECTION.md](SEASON-DIRECTION.md).

---

## 1. Tylne skrzydło najpierw (domyślnie trzy elementy)

Zaczynamy od tylnego, bo to najprostsza dźwignia „więcej tyłu” przy naszym starcie z przodu. Domyślna ścieżka to **trzy elementy** na bazie 017, z **zamrożonym endplate** na czas serii kątów i slotów. **Cztery elementy** — najwyżej jedno porównanie obok najlepszego 3-el., nie nowa baza.

Na aucie we Fluencie kręć **po jednym parametrze**, w tej kolejności:

1. kąty main / klap,  
2. overlap,  
3. gap (szczelina),  
4. dopiero potem 1–2 warianty endplate (packaging), gdy sloty już mają sens.

**Z literatury (cytaty, nie targety):** Staniszewski w 2D izolowanym używał kroków rzędu main **1,5°**, klapy **2°**, overlap **10 mm**, gap **+5 / +10 mm**; u niego overlap **−30 mm** był najlepszy, a **−40 mm** już gorszy. Jackson ostrzega przed pchaniem w stall — u niego overall ok. **22,8°** było optimum, stall ok. **25°** (inna geometria, inne auto). Szczegóły: [sources/research-h1-overlap-gap-deep-dive.md](sources/research-h1-overlap-gap-deep-dive.md), [sources/research-season-geometry-profiles.md](sources/research-season-geometry-profiles.md), [sources/research-rw-endplate-packaging.md](sources/research-rw-endplate-packaging.md).

**Kill na RW:** Cx rośnie mocno **bez** zysku |Cz| (ścieżka stall / zły AOA) — case odpada, nawet jeśli „ładnie wygląda”.

Plan kampanii: [SPEC-FLUENT-H1-RWITER017.md](SPEC-FLUENT-H1-RWITER017.md).  
Checklista: [sources/checklist-h1-fluent-rw.md](sources/checklist-h1-fluent-rw.md).

---

## 2. Potem podłoga

Jak tył przestanie być oczywistym wąskim gardłem, bierzemy podłogę.

Najpierw **throat** (gdzie siada peak podciśnienia — to dźwignia balansu) i **kąt dyfuzora**. Z Chalmersa (cytat): wybrali **13°** zamiast **19°**, bo lepiej trzyma się na prostej, hamowaniu i w zakręcie — nie dlatego, że 13° daje absolutne maksimum w jednym punkcie. Dopiero potem **strakes / side floors**. Przed zamrożeniem kształtu zróbcie **mapę yaw / ride height**.

**Ostrzeżenie z cudzego auta (nie nasze Δ%):** Lisboa raportuje rozrzut rzędu ok. **20%** −CL·A przez ride height i ok. **16%** DF przez yaw — czyli podłoga lubi umierać poza „ładnym” punktem na wprost. Szczegóły: [sources/research-h2-undertray-balance-levers.md](sources/research-h2-undertray-balance-levers.md), [sources/research-h2-strakes-yaw-rideheight.md](sources/research-h2-strakes-yaw-rideheight.md).

Nie optymalizujcie podłogi samym peakiem na prostej — Endurance to zabija.

---

## 3. Przednie dopiero na końcu

**H3** to odciążenie **przedniego skrzydła** — ruszacie je **dopiero gdy** po RW + podłodze balans nadal siedzi wyraźnie powyżej ok. **52%** na przód. Odciążanie FW może cofnąć balans, ale łatwo przy okazji zjeść całe |Cz| — dlatego to ostatnia dźwignia, nie pierwsza. **Wąsy** zostają osobno (później / TBD, H4), nie w tej samej serii co H3.

**S1223** z literatury to kandydat pod wąsy / lokalne detale FW, **nie** baseline całego przedniego. Notatka: [sources/research-h3-fw-unload-for-balance.md](sources/research-h3-fw-unload-for-balance.md).

---

## Jak oceniasz, czy case jest dobry (nasza karta)

Po każdym sensownym case’ie Fluenta, przy tych samych Aref / Lref / punkcie momentu co na karcie:

- |Cz| co najmniej **3,682**,  
- Cx około **1,23** lub lepiej,  
- balans bliżej **48–52%** na przód niż dzisiejsze ~62%.

Raportujcie **ΔCx / ΔCz / Δbalans**, a nie tylko jeden „ładny” peak. Patrzcie też na Cp i separację — sam współczynnik bez obrazu przepływu łatwo okłamuje.

Jeśli opór wystrzelił albo balans poszedł jeszcze bardziej na przód — to nie jest ulepszenie.

---

## Cztery poprawki workflow (żeby seria miała sens)

1. **Parametryczny CAD** i jedna wspólna tabela case’ów / hipotez (co zmieniliście i po co).  
2. **Jeden zamrożony setup** Fluent na serię: Aref, znaki, siatka / wall treatment — bez mieszania przepisów między punktami.  
3. Raportujcie **delty i fizykę** (Cp, stall), nie pojedynczy absolut wyjęty z kontekstu.  
4. Po CFD: **nitki / flow-vis**, później tor lub tunel — sama siatka nie zamyka tematu.

Z procesu AMZ bierzemy **kulturę iteracji** (dużo CFD + tunel), **nie** ich Cl. Notatka: [sources/research-amz-berlin-snails-aero.md](sources/research-amz-berlin-snails-aero.md).  
Więcej o workflow w repo: [WORKFLOW.md](WORKFLOW.md).

---

## Czego świadomie nie robimy

- ruchomego DRS,  
- wentylatora spod podłogi,  
- przenoszenia Cl z 2D OpenFOAM na kartę auta,  
- kopiowania cudzych Cl/Cd jako naszych targetów,  
- mieszania kilku dźwigni w jednym case’ie.

---

## Jak czytać to repo

Najpierw [README.md](README.md) i ta strona, potem [SEASON-DIRECTION.md](SEASON-DIRECTION.md) i [TARGETS.md](TARGETS.md).  
[MAPA-REPO.md](MAPA-REPO.md) to spis folderów — dodatek, gdy szukasz konkretnego pliku.

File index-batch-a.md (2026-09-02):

# FS Aero KB — index batch A

Trzy ekstrakty wiedzy z prac dyplomowych PUT Motorsport (Formula Student), stan: 2026-09-01.

## Źródła

1. **[staniszewski-2023-wing.md](sources/staniszewski-2023-wing.md)** — Alex Staniszewski, inżynierska 2023, tylne skrzydło wieloprofilowe.
   CFD 2D/3D (Fluent, Realizable k-ε, 15 m/s) optymalizuje kąty, overlap i gap trzech elementów RW oraz adresuje nierównomierny Cp w środku rozpiętości.
   Najlepsze 2D podnoszą |Fz| z ok. **398 N** do ok. **560–565 N** na izolowanym skrzydle.
   Na pojeździe Cx/Cz (ok. **0,72** / **−2,03**) zmieniają się tylko marginalnie.

2. **[staniszewski-2024-energy.md](sources/staniszewski-2024-energy.md)** — Alex Staniszewski, magisterska 2024, wpływ aero na zużycie energii EV FS.
   Mapy Cx/Cz vs kąt skrętu + model toru pokazują, że podłoga jest wrażliwa na δ≠0.
   Pełny pakiet vs FW&RW daje ok. **2,7%** niższą średnią siłę hamującą (proxy energii) mimo ok. **+10 kg** masy UT.

3. **[naglowski-2024-package.md](sources/naglowski-2024-package.md)** — Kacper Nagłowski, inżynierska 2024, modyfikacje pakietu (wąsy Selig S1223).
   Seria CFD @15 m/s: baseline Cz = **−4,071** / Fz = **−561 N**.
   Najlepsza iter111.4 osiąga Fz = **−565 N** przy Cx = **1,480** i balansie ok. **57%** przód.
   Wąsy zwiększają docisk auta mimo własnej nośnej i cofają balans, chroniąc RW / wspierając UT.

## Ścieżki plików (w tym repo)

- `sources/staniszewski-2023-wing.md`
- `sources/staniszewski-2024-energy.md`
- `sources/naglowski-2024-package.md`
- `index-batch-a.md`

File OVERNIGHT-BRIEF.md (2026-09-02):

# Overnight brief — PUTM aero (rano dla Mikołaja)

**Kiedy:** research w nocy 1/2 IX 2026 (Europe/Warsaw).
**Kotwica zamrożona:** `RWiter017`.

Liczby startowe (bez zmian względem Spec):

- Cx = **1,229**
- |Cz| = **3,682**
- balans ≈ **61,6%** na przód → cel około **50%**
- Aref half-car = **0,50 m²**
- DRS ruchomy = **OUT**
- wentylator spod podłogi = **OUT**
- kolejność pracy: **H1 tylne skrzydło**, potem **H2 podłoga**

---

## Co zrobiliśmy

Dwie nowe notatki po polsku w `sources/` oraz wpisy w `INDEX.md`:

1. **`sources/research-overnight-rw-multi-element.md`** — porównanie 3 vs 4 elementów tylnego skrzydła, kąty / gap / overlap, DRS aktywny vs pasywny, kontekst **EU FS Rules 2026 T8**.
2. **`sources/research-overnight-ut-yaw-balance.md`** — podłoga i dyfuzor a balans i yaw; Staniszewski **2024** oraz Chalmers 2021, OSU Jensen 2010, Jowsey/Passmore; implikacje dla Autocross i Endurance.
3. Równolegle w repo jest też **`sources/research-papers-rw-ut-yaw-clcd.md`** (zbiorcza notatka paperów 3 vs 4 / UT+yaw / Cl/Cd). Warto czytać razem z punktami 1–2.

## Co wyszło (skrót)

### Tylne skrzydło / H1

Domyślny układ high-docisk w literaturze Formula Student to nadal **trzy elementy**.
Z Jacksona, McBeatha i Staniszewskiego 2023:

- profil E423 u Jacksona;
- gap **1–4%** cięciwy, overlap **1–6%** cięciwy;
- Staniszewski 2D: obniżanie main i overlap ok. **−30 mm**;
- na aucie coupling body↔RW zabija naiwny transfer 2D → 3D.

**Cztery elementy** pojawiają się jako wynik optymalizacji (Novais / Aveiro) oraz jako ścieżka „cascade” (LUT / Metropolia EV).
To sensowna hipoteza CAD w limicie T8, **bez** gotowej liczby ΔCz dla RWiter017.

Aktywny DRS w paperach mocno tnie opór skrzydła, ale u nas zostaje **OUT**.
Najwyżej rozważamy stały low-drag setup „pasywny” — osobno, poza peak-dociskiem.

### Podłoga / H2

Staniszewski 2024: podłoga i sekcje boczne są **mocno wrażliwe na yaw**; skrzydła są względnie „płaskie”.
Mimo to pełny pakiet wygrywa |Cz| w całym zakresie kąta skrętu.

Z paperów:

- proxy energii **−2,7%** z podłogą mimo ok. **+10 kg** (Staniszewski);
- Chalmers: dyfuzor pod **odporność** (prosta / hamowanie / zakręt), nie sam peak; ok. **13°** bywało bezpieczniejsze niż **19°**; strakes i side floors pomagają w cornering;
- OSU: lokalizacja throat to dźwignia środka ciśnienia / balansu; yaw **5°** może podnieść docisk; +**1°** roll → docisk ok. **−6%**;
- Multi-channel (Jowsey) rozszerza envelope kąta.

### Regulamin

T8 2026 nie banuje wprost ruchomego aero; nasz DRS OUT to decyzja Spec.
Fan OUT bez zmian (Michalecki + limit 500 W to osobna historia).

## Co nadal otwarte

- Brak bezpośredniego porównania **3 vs 4 elementy** na pakiecie RWiter017 (tylko hipoteza CAD).
- Brak naszej mapy **Fz_UT / yaw** na aktualnym bolidzie (Staniszewski to inny pakiet; wykresy bez pełnych tabel w plain text).
- „Pasywny DRS” 019/020 — hasło Spec bez świeżego ekstraktu liczb w `sources/`.
- Transfer Cl/Cd z Aveiro / LUT / Chalmers / Jackson jest **zakazany** — inne Aref, prędkości i geometrie.

## PDF / dropy, które warto wrzucić rano

1. **LUT** `lutpub.lut.fi/10024/171732` (pełny PDF — bot-wall przy fetch).
2. **Novais** Aveiro PDF (`ria.ua.pt/.../Documento_Pedro_Novais.pdf` — TLS padał z boxa).
3. **MDPI Fluids** `10.3390/fluids7090309` (CDN block).
4. Ewentualnie ponownie **Staniszewski 2024** PDF + arkusz → odczyt Cx(δ)/Cz(δ) z rysunków.
5. Lokalne **019/020** i postprocessing udziału **UT na 017**, jeśli leżą na OneDrive.

## Proponowany następny ruch (gdy wstaniesz)

Nie rozstrzygamy CAD w briefie — tylko kolejka:

1. **H1:** seria kątów / gap / overlap na **trzech** elementach na bazie 017 (guardrail z TARGETS).
2. Równolegle lekki CAD **4-elementowy** do jednego case’u porównawczego.
3. Potem **H2** z minimum δ = 0 oraz 1–2 punktami yaw / kąta skrętu — nie sam peak na prostej.

## Noc 2 (2026-09-01 wieczór)

Notatka AMZ / FaSTTUBe / Running Snail jest już na main (`sources/research-amz-berlin-snails-aero.md`).
Następny research — odciążenie przedniego skrzydła (H3) oraz szczeliny skrzydła tylnego — jest w toku.
Smoke OpenFOAM (~312k komórek) pozostaje poza kartą Spec.

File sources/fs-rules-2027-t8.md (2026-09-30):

# Formula Student Rules 2027 — T8 aero (claims z cytatami + diff vs 2026 v1.1)

**Źródło:** *Formula Student Rules 2027 — Aerodynamics Extract* (EN), stopka: „Source: Formula Student Rules 2027 Version 1.0, uploaded by the user.”  
**PDF:** `team/rules-2027-aero-extract.pdf` · **dump tekstowy:** `team/rules-2027-aero-extract.txt`  
**Poprzedni sezon (do porównania):** [fs-rules-2026-t8.md](fs-rules-2026-t8.md) · `team/rules-raw.txt`  
**Loophole'y / szare strefy 2027:** [rules-2027-aero-loopholes.md](rules-2027-aero-loopholes.md)  
**Boxy w CAD (STEP):** [`team/cad-boxes/`](../team/cad-boxes/README.md)

Tu tylko **cytaty, claims i różnice**. Decyzje projektu = Spec / lead, nie ten plik.

---

## ⚠️ Status źródła

| Fakt | Pewność |
|---|---|
| Plik to **wyciąg** (ReportLab, autor anonimowy, utworzony 2026-09-30), **nie** oficjalny PDF FS | **high** (metadane PDF) |
| Brak rysunków (Fig. 3, Fig. 5, figura envelope T 8), brak changelogu, brak numeru strony oryginału poza „Original rules: pp. …” | **high** |
| Brak w wyciągu: **T 11.11.1** (wentylatory 500 W), **T 11.12.3** („box defined in T 8.2”), **T 9** (CGS/HPHS), T 2.3.3 (vent holes), T 1.1.16 | **high** — brak w wyciągu **≠** usunięte z regulaminu |
| IN 1.5.1 w wyciągu kończy się na „(De-)Coupling of actuators…” — w 2026 lista ma jeszcze 2 punkty (sensor covers, LV batteries) + zdanie o innych modyfikacjach | **high** — prawdopodobnie przycięte, nie zmienione |

**Przed zamrożeniem CAD/CFD na 2027:** potwierdzić każdy wiersz „ZMIANA” poniżej w **pełnym oficjalnym PDF 2027** (+ Fig. 5 i figura T 8) i Rules Q&A.

---

## Diff 2026 v1.1 → 2027 (wyciąg)

| Reguła | 2026 v1.1 | 2027 | Status |
|---|---|---|---|
| **T 2.1.3** keep-out kół — zasięg boczny | od *outside plane* do *inboard plane* koła | *„extends laterally outward from the inboard plane of the wheel/tire assembly **indefinitely**”* | **ZMIANA** (ostrzej) |
| **T 2.1.3** keep-out przy tylnych kołach — wysokość | brak limitu wysokości | *„…at the rear tires extends up to **700 mm** above the ground”* | **ZMIANA** |
| **T 2.1.3** dodatkowa strefa | — | od góry tylnej opony do **700 mm**, **150 mm inboard** od inboard plane tylnej opony; wzdłużnie w granicach strefy 75 mm tylnej opony | **NOWE** |
| **T 2.1.4** variable keep-out | — | przed płaszczyzną przez *leading edge* przednich opon: 2 niezależne, nieprzecinające się prostopadłościany **75 × 250 mm × ∞**, jedna ściana na ziemi, równoległe do osi auta, nie outboard od przednich opon (Fig. 5) | **NOWE** |
| **T 8.2.1** strefa przednia | przed **HR**: <500 mm; przed **osią** i outboard od most inboard front tire: <250 mm | przed płaszczyzną przez **leading edge przednich opon**: <**350 mm** (cała szerokość) | **ZMIANA** |
| **T 8.2.1** strefa środkowa | (mieściła się w „przed HR <500 mm”) | *„All other”* (między LE przednich opon a HR): poniżej płaszczyzny przez **górne punkty opon** (przód+tył, strona bliższa urządzeniu) | **ZMIANA** (ostrzej) |
| **T 8.2.1** za HR | <1,1 m | <**1100 mm** | bez zmian |
| **T 8.2.2** nisko | <500 mm i za **osią** → do płaszczyzny most outboard przód+tył | **poniżej góry opon** i za **LE przednich opon** → to samo | **ZMIANA** (próg + granica) |
| **T 8.2.2** pas pośredni | (część „>500 mm”) → nie outboard od **most inboard** tylnej opony | **góra tylnych opon … 700 mm** → min. **150 mm inboard** od most inboard tylnej opony | **ZMIANA** (ostrzej) |
| **T 8.2.2** wysoko | >500 mm → nie outboard od **most inboard** tylnej opony | **700 … 1100 mm** → nie outboard od **most outboard** tylnego koła/opony | **ZMIANA** (dużo luźniej) |
| T 8.2.3 długość | 250 mm za / 700 mm przed | 250 mm za / 700 mm przed | bez zmian |
| T 8.2.4 warunek pomiaru | koła prosto, any suspension setup, z/bez kierowcy | to samo | bez zmian |
| T 8.1.1 definicja | aero device / mounting | to samo | bez zmian |
| T 8.3.1–2 sztywność | 200 N / 225 cm² ≤10 mm; 50 N ≤25 mm | to samo | bez zmian |
| T 1.1.2, T 1.1.18 | bodywork / surface envelope | to samo | bez zmian |
| T 2.1.2, T 2.2.1–2, T 2.3.2, T 2.3.4, T 2.4.1 | 30 mm GC, zakaz skirtów, concave, R38, R3/R1 | to samo | bez zmian |
| T 3.19.4, T 3.20.1–2 | IA + non-crushable, attachment za AIP | to samo | bez zmian |
| A 6.6.8 | 2 osoby przy FW przy pchaniu | to samo | bez zmian |
| IN 1.5.1 | kąty winglet'ów po Tech OK, pozycja urządzenia nie | to samo (lista przycięta) | bez zmian |

---

## Claims (claim | cytat / dowód | confidence)

| claim | evidence | confidence |
|---|---|---|
| Aero przed płaszczyzną przez LE przednich opon: **< 350 mm** od ziemi, bez podziału inboard/outboard | T 8.2.1 b1 | **high** (wyciąg) |
| Aero za płaszczyzną HR (front face support, bez padów, most rearward): **< 1100 mm** | T 8.2.1 b2 | **high** |
| Pozostałe aero (między LE przednich opon a HR): poniżej *virtual horizontal plane* przez górne punkty obu opon po stronie bliższej urządzeniu | T 8.2.1 b3 | **high** (tekst); geometria płaszczyzny przy różnych OD przód/tył = **TBD** |
| Aero poniżej góry opon i za LE przednich opon: nie szersze niż pionowa płaszczyzna styczna do most outboard przód i tył | T 8.2.2 b1 | **high** |
| Aero między górą tylnych opon a 700 mm: min. **150 mm inboard** od most inboard tylnej opony | T 8.2.2 b2 | **high** |
| Aero 700–1100 mm: do **most outboard** punktu tylnego koła/opony (pełna szerokość auta) | T 8.2.2 b3 | **high** |
| Keep-out kół ±75 mm (side view) biegnie od inboard plane koła **na zewnątrz bez końca**; przy tylnych kołach do 700 mm | T 2.1.3 b2 | **high** |
| Dodatkowy keep-out: góra tylnej opony → 700 mm, 150 mm inboard od inboard plane tylnej opony, wzdłużnie w strefie 75 mm | T 2.1.3 b3 | **high** |
| Przed LE przednich opon: 2 prostopadłościany 75 × 250 mm × ∞ na ziemi, nie outboard od przednich opon; żadna część auta nie może w nie wejść | T 2.1.4 | **high** (tekst); **który wymiar to wysokość** i **kto wybiera położenie** = **TBD** (Fig. 5 brak) |
| Długość: max 250 mm za tylnymi oponami, max 700 mm przed przednimi | T 8.2.3 | **high** |
| Sztywność, GC 30 mm, zakaz kontaktu z torem, promienie krawędzi — jak w 2026 | T 8.3, T 2.2, T 2.4.1 | **high** |
| Szerokość aero **przed** LE przednich opon nie jest ograniczona w T 8.2.2 (tylko T 2.1.3 / T 2.1.4 / T 8.2.3) | T 8.2.2 b1 obejmuje tylko *„further rearward than a vertical plane through the leading edge of the front tire”* | **high** (cisza w wyciągu); całość = **TBD** (pełny PDF) |
| Wentylatory ≤500 W, DRS/active aero | **brak w wyciągu** — nie wnioskujemy | **low** (brak danych) |

---

## Cytaty kluczowe (z wyciągu)

**T 8.2.1** — *„All aerodynamic devices forward of a vertical plane through the leading edge of the front tires must be lower than 350 mm from the ground.”* · *„All aerodynamic devices rearward of a vertical plane through the rearmost portion of the front face of the driver head restraint support, excluding any padding, set to its most rearward position must be lower than 1100 mm from the ground.”* · *„All other aerodynamic devices must be lower than the virtual horizontal plane defined by the topmost points of the two tires on the left or right side of the vehicle, whichever side is closer to the device.”*

**T 8.2.2** — *„All aerodynamic devices lower than the topmost points of the tires and further rearward than a vertical plane through the leading edge of the front tire, must not be wider than a vertical plane touching the most outboard point of the front and rear wheel/tire.”* · *„All aerodynamic devices between the top edge of the rear tires and 700 mm above the ground, must not be wider than 150 mm inboard of the most inboard point of each rear tire.”* · *„All aerodynamic devices between 700 mm and 1100 mm above the ground, must not extend outboard of the most outboard point of the rear wheel/tire.”*

**T 2.1.3** — *„This keep-out zone extends laterally outward from the inboard plane of the wheel/tire assembly indefinitely. The keep-out-zone at the rear tires extends up to 700 mm above the ground.”* · *„An additional keep-out-zone extends from the top of the rear tire to 700 mm above the ground and 150 mm inboard from the inboard plane of the rear tire. It is bounded longitudinally by the 75 mm keep-out-zone of the rear tire.”*

**T 2.1.4** — *„No part of the vehicle forward of the vertical plane through the leading edge of the front tires must enter the variable keep-out zone, see Figure 5. It is defined by two independent, non-intersecting, cuboids of 75 mm × 250 mm × infinite length. One infinite-length face must rest on the ground, and the infinite-length edges must be parallel to the vehicle longitudinal axis. The cuboids must not extend outboard of the front tires.”*

---

## Implikacje jako fakty z tekstu (bez decyzji Spec)

- **RW:** część 700–1100 mm może sięgać do **zewnętrznej** krawędzi tylnych opon (2026: do wewnętrznej). Część między górą tylnej opony a 700 mm jest **węższa** niż w 2026 (−150 mm na stronę). Endplate na pełnej szerokości nie może więc zejść poniżej 700 mm (oprócz okna za strefą keep-out opony — patrz loophole'y).
- **Strefa za HR wysoko (700–1100 mm) jest pełnej szerokości także przed tylnymi oponami** — nie tylko nad/za nimi.
- **FW:** centrum 500 → **350 mm**; outboard 250 → **350 mm**; granica strefy przesunięta z osi na **LE przednich opon**. Elementy FW za LE przednich opon (inboard) podlegają limitowi „góra opon”.
- **Środek auta (sidepody, SW, lotki boczne, wysokie części UT) między LE przednich opon a HR:** limit wysokości = **góra opon** (w 2026: 500 mm). Liczba mm = z CAD (OD opon), nie z PDF.
- **Keep-out kół:** nic (także outboard) w pasie ±75 mm przed/za oponą → wąsy / lotki „obok koła” / szerokie endplate'y FW w tym pasie = nielegalne.
- **T 2.1.4:** pod FW / nosem muszą zostać dwa wolne „kanały” 75 × 250 mm. Orientacja i sposób ustawienia (zespół czy Tech) = **pytanie nr 1 do Q&A** — w najgorszym wariancie wymusza ≥75 mm prześwitu FW na prawie całej szerokości.
- Brak wymiarów naszego auta w repo (OD opon, track, pozycja HR, obecna rozpiętość RW / wysokość SW) → przeliczenie boxów w mm = **pomiar z CAD**.

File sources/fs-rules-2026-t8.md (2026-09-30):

# Formula Student Rules 2026 v1.1 — T8 aero (claims z cytatami)

> **⚠️ 2027:** ten plik opisuje **FS Rules 2026 v1.1**. W wyciągu 2027 zmieniły się T 8.2.1–2 (350 mm przód, „góra opon” w środku, RW 700–1100 mm na pełną szerokość, pas 150 mm inboard) oraz T 2.1.3–4 (keep-out). Diff i cytaty: [fs-rules-2027-t8.md](fs-rules-2027-t8.md).

**Źródło:** *Formula Student Rules 2026*, Version **1.1**  
**PDF:** `team/rules-current.pdf` · **dump tekstowy:** `team/rules-raw.txt`  
**Brief z boxami / lukami (Aero Pack):** [rules-aero-boxes-loopholes.md](rules-aero-boxes-loopholes.md)

Tu tylko **cytaty i claims**. Decyzje projektu (DRS IN/OUT, fan OUT) = Spec / lead, nie ten plik.

---

## Claims (claim | cytat / dowód | confidence)

| claim | evidence | confidence |
|---|---|---|
| Dokument = FS Rules **2026 Version 1.1** | nagłówek stron w dumpie („Version: 1.1”) | **high** |
| Aero device = struktura celowo prowadząca przepływ (DF i/lub drag); mounting nie jest aero, *unless intentionally designed to be one* | T 8.1.1 | **high** |
| Przed head-restraint (front face support, bez padów, most rearward): wysokość aero **&lt; 500 mm** od ziemi | T 8.2.1 | **high** |
| Przed osią przednią i outboard od most inboard front tire/wheel: wysokość **&lt; 250 mm** | T 8.2.1 | **high** |
| Za head-restraint: wysokość aero **&lt; 1,1 m** od ziemi | T 8.2.1 (+ Fig. 14: 1100 mm) | **high** |
| Aero **&lt;500 mm** i za osią przednią: nie szersze niż płaszczyzna styczna do most outboard opon przód **i** tył | T 8.2.2 | **high** |
| Aero **&gt;500 mm**: nie outboard od most inboard **tylnej** opony/koła | T 8.2.2 | **high** |
| Max **250 mm** za rearmost part of rear tires; max **700 mm** przed fronts of front tires | T 8.2.3 | **high** |
| Envelope musi być spełniony przy kołach prosto i **any suspension setup**, z kierowcą i bez | T 8.2.4 | **high** |
| Sztywność: 200 N / ≥225 cm² → ugięcie ≤10 mm; 50 N w dowolnym punkcie/kierunku → ≤25 mm | T 8.3.1–2 | **high** |
| Min. static ground clearance **30 mm** (oprócz opon), z kierowcą; active suspension → najniższa pozycja | T 2.2.1 | **high** |
| Zakaz sliding skirts / aero, które *by design, fabrication or as a consequence of moving* kontaktują tor | T 2.2.2 | **high** |
| Active devices designed to move air (w tym cooling fans): łączna moc znamionowa **≤ 500 W** (wyjątek CV 1.8) | T 11.11.1 | **high** |
| W T 8 **brak** explicite zakazu „movable aerodynamic devices” / DRS | przeszukanie T 8 w dumpie — cisza | **high** (cisza); legalność całościowa = **TBD** (Q&A / Scrutineering) |
| Box **800×500 mm** jako envelope endplate/wing **nie występuje** w tym PDF | brak w T 8; „box defined in T 8.2” = envelope T 8.2/Fig.14 (T 11.12.3) | **high** |

---

## Cytaty kluczowe (skrót z raw)

**T 8.1.1** — *„A specifically designed structure mounted on the vehicle to guide the airflow around the vehicle, increasing the downforce acting on the vehicle and/or lowering its drag. The mounting of this structure is not regarded as an aerodynamic device, unless it is intentionally designed to be one.”*

**T 8.2.1 (FW / przed HR)** — *„…must be lower than 500 mm from the ground.”* · outboard przed osią: *„…must be lower than 250 mm from the ground.”* · za HR: *„…must be lower than 1.1 m from the ground.”*

**T 8.2.2** — poniżej 500 mm za osią przednią: *„…must not be wider than a vertical plane touching the most outboard point of the front and rear wheel/tire.”* · powyżej 500 mm: *„…must not extend outboard of the most inboard point of the rear wheel/tire.”*

**T 2.2.2** — *„Sliding skirts or other aerodynamic devices that by design, fabrication or as a consequence of moving, contact the track surface are prohibited.”*

**T 11.11.1** — *„The maximum combined total rated power of any active devices designed to move air is 500 W, this includes cooling fans but does not apply to CV 1.8.”*

Pełniejsza tabela boxów + loophole’y z oceną ryzyka: [rules-aero-boxes-loopholes.md](rules-aero-boxes-loopholes.md).

---

## Implikacje tylko jako fakty z tekstu (bez decyzji Spec)

- Nasz RW (&gt;500 mm) siedzi w **wąskim** boxie (inboard tylnej opony), max **1,1 m**, max **250 mm** za oponami.
- Fan **nie jest zakazany** — jest limit **500 W**; „fan OUT” u nas to decyzja osiągów (Michalecki), nie ban z T 8.
- DRS: **cisza w T 8** + limity kontaktu z torem / envelope przy każdym setupie / sztywność / ewentualnie T 9 — nie „automatycznie OUT”.

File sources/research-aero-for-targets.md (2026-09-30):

# Research: ogólne rady aero pod cele Spec (PUT Motorsport / putm-aero)

> **⚠️ 2027:** tabele T 8.2 tutaj to **2026 v1.1** („wąski box szerokości” RW już nieaktualny — 2027: 700–1100 mm do zewnętrznej krawędzi tylnych opon; FW <350 mm). Patrz [fs-rules-2027-t8.md](fs-rules-2027-t8.md).

**Status:** notatka robocza do Spec (2026-09-01)  
**Język:** PL

**Cel tej notatki:** zebrać **ogólne** rady aero (nie plan CAD/CFD) pod **nasze** targety i mapować je na hipotezy **H1–H4**.

**Kotwica liczbowa** (`RW_iter017`, kontekst **15 m/s**):

- Cx = **1,229**
- Cz = **−3,682**
- Cm = **−0,429**
- balans ≈ **61,6%** przód (`1/2 + Cm/Cz`)

**Hard targety:**

- |Cz| ≥ **3,682**
- Cx ≲ **1,23**
- balans **48–52%** przód (≈ **−12 pp** od 61,6%)

**Zakres zamrożony Spec:** DRS ruchomy **OUT** (pasywne klapy — osobna gałąź oporu); fan spod podłogi **OUT**; wąsy **TBD**; priorytet **Endurance + Autocross**; rozważyć RW **4-elementowe**.

**Aref** (powierzchnia odniesienia): nie inventujemy. Fluent i OpenFOAM porównujemy dopiero po Reference Values z Fluenta.

Powiązane: [research-balance-shift.md](research-balance-shift.md), [research-fs-teams-practice.md](research-fs-teams-practice.md) (jeśli w repo), [TARGETS.md](../TARGETS.md), [fs-rules-2026-t8.md](fs-rules-2026-t8.md).

---

## 0. Co optymalizujemy (słowa Spec → metryki CFD)

| Decyzja Spec | Metryka / guardrail | Źródło |
|---|---|---|
| Max docisk przy możliwie niskim oporze | \|Cz\| ≥ **3,682**, Cx ≲ **1,23** @ 15 m/s | TARGETS / RW_iter017 |
| Cofnąć balans ~**12 pp** (61,6% → ~50/50) | Balans Front = `1/2 + Cm/Cz` (arkusz) przy **x = 0,765 m**, Lref **1,53 m** | research-balance-shift; team-rwiter017 |
| Endurance + Autocross | Nie tylko peak @ δ=0 — mapa Cx/Cz vs δ + model toru (energia = proxy F_ham) | Staniszewski 2024 |
| Ruchomy DRS OUT; fan OUT | Nie projektować peak-DF przez open DRS ani ssanie wentylatora | Decyzja 2026-09-01; Michalecki |
| RW 4-el. do rozważenia | Więcej parametrów setupu tyłu; koszt masa/sztywność/T8.3 | Spec + Quintanas 2023 (UPC) |

**Zasada dźwigni (kolejność):** **H1 RW → H2 UT → H3 odciążenie FW tylko jeśli trzeba → H4 wąsy TBD**. Nie dokręcać samego FW „żeby dogonić docisk” — to pcha balans jeszcze bardziej na przód.

---

## 1. H1 — tylne skrzydło (główna dźwignia balansu tyłu)

### 1.1 Czego uczą źródła PUT / Jackson (3 elementy)

W źródłach lokalnych RW jest **3-elementowe**:

- **Staniszewski 2023:** izolowane 2D — obniżanie kąta main względem baseline **7,5°** podnosi |Fz| (baseline Fz ≈ **−398 N** → przy −6,5° ≈ **−502 N**); overlap ≈ **−30 mm** daje szczyt ≈ **−565 N**; **−40 mm** już pogarsza. Gap **+5/+10 mm** utrzymuje wysoki DF przy niskim Fx. Na **całym pojeździe** Cx/Cz prawie stoją (**~0,72 / −2,03**) — autor ostrzega przed **couplingiem** RW↔body / element boczno-przypodłogowy i niepewnością CFD.
- **Jackson 2018:** 3 el., E423, gap/overlap wg McBeath (**1–4%c** / **1–6%c**); AOA overall **22,81°** (flaps **28°/60°**) przed stall ~**25°**. Na pojeździe DRS closed: CL_DF **1,15**, CD **1,21**; DRS open: CL **0,26**, CD **0,79** (−**35%** siły oporu). U nas DRS ruchomy **OUT** — liczby open służą tylko jako ostrzeżenie: low-drag setup **zjada** peak |Cz|.

**Wniosek H1:** więcej docisku z tyłu przez kąty / overlap / gap / (ew. 4. element) — **zawsze na pakiecie**, nie tylko 2D. Pilnować Cx ≲ 1,23 i |Cz| ≥ 3,682.

### 1.2 3 vs 4 elementy — co da się powiedzieć bez inventowania

| Claim | Evidence | Confidence |
|---|---|---|
| Źródła PUT w KB (Staniszewski 2023, Jackson) = **3** elementy; brak lokalnych liczb „4 el. bije 3 o X%” na naszym Aref | ekstrakty KB | **high** |
| 4. element zwiększa liczbę parametrów setupu (kąty + gurney na ostatnich foils) i pozwala eksponować ostatni flap na czystsze powietrze | Quintanas / Dynamics UPC 2023: „fourth foil… increase the number of parameters”; setup pod Accel/Skid/AX/Endurance | **high** (motywacja); **med** transfer na 017 |
| Multi-element pozwala wyższe AOA bez stall przez re-energizację BL (slotted flaps) | Jackson cyt. McBeath; Quintanas § slotted flaps; NablaFlow (F1 context, jakościowo) | **high** kierunek |
| McBeath (przez Jackson): gap **1–4%c**, overlap **1–6%c**; flap1 ~**25–30°**, flap2 ~**30–70°** jako start do optymalizacji AOA | Jackson 2018 § multi-element | **high** jako start; **med** na 4-el. (więcej szczelin) |
| 4-el. kosztuje: masa, formy, sztywność T8.3, coupling z body (lekcja Staniszewski: 2D≠3D) | Quintanas: masa RW ~**7 kg** real; Staniszewski coupling; T 8.3.1–2 | **high** ryzyka |
| LUT / Metropolia 2026 (teza): DF z RW poprawia cornering mimo nieliniowego wzrostu drag — priorytet \|CL\| pod lap, nie ślepy L/D | LUTPUB abstract (HPF026) | **med** (kierunek eventowy AX/Endurance) |

**Rada Spec (H1):** traktować **4-el.** jako **hipotezę setupu i peak tyłu**, nie jako gwarantowany zysk Cx/Cz. Gate: tabela Δbalans / ΔCx / ΔCz na pakiecie 017 vs 3-el. baseline; nie przenosić optimum 2D 1:1.

### 1.3 Gurney (narzędzie fine-tune tyłu / ostatnich elementów)

| Claim | Evidence | Confidence |
|---|---|---|
| Gurney na TE zwiększa CL (efektywny camber / cyrkulacja) przy koszcie CD | ICAS 2006 (2-el.); PMC4897339; Quintanas: gurney na 3. i 4. foil w Design Manager | **high** kierunek |
| Wysokość ~**1–2%** lokalnej cięciwy: dobry L/D; **>2%** — drag rośnie ostro | PMC / numerical Gurney studies (1%c, 2%c vs 4%c) | **high** literaturowo; **med** na naszym RW |
| Montaż blisko TE (≤~10%c od TE) | PMC4897339 | **med–high** |
| U nas: gurney na **ostatnich** elementach RW = tani sposób dołożyć tył bez redesignu całego main — ale pilnować Cx ≲ 1,23 | mapowanie na H1 + guardrail Spec | **med** (hipoteza projektowa) |

---

## 2. H2 — undertray / dyfuzor (druga dźwignia + energia Endurance)

### 2.1 Udział i kierunek balansu

Z **Nagłowski 2024** (inny model niż 017 — **kierunki**, nie targety):

| Komponent | Fz @ 15 m/s | Udział ≈ |
|---|---:|---:|
| FW | **−221 N** | ~**39%** |
| UT | **−202 N** | ~**36%** |
| RW | **−135 N** | ~**24%** |
| Fz_all | **−561 N** | 100% |

Balans baseline **60,3%** przód → z wąsami best **57,3%** (kilka pp). UT to duży, często „tylny” kawałek Fz.

**Staniszewski 2024:** pełny pakiet (FW+RW+**UT&SW**) ma **wyższe |Cz| dla każdego** δśrd vs FW&RW; Cx(δ) przecina się (~niższy Cx pełnego pakietu **0–10°**, wyższy **10–20°**). Po modelu toru: średnia siła hamująca **F2/F1 = 0,973** → **−2,7%** mimo **+~10 kg** masy UT — proxy energii Endurance (**high** jako F_ham; **med** jako Wh).

### 2.2 Yaw / steer / ride height — ostrzeżenia praktyczne

Yaw = kąt „bokiem do napływu”, jak w zakręcie. Podłoga na to mocno reaguje.

| Claim | Evidence | Confidence |
|---|---|---|
| **UT&SW silnie wrażliwe** na kierunek napływu; nominal ~0°; przy δ≠0 istotny spadek sił z podłogi; FW/RW „płaskie” | Staniszewski 2024 s. 55–56 | **high** |
| Nie ekstrapolować zakrętu z samego δ=0 | Staniszewski 2024 Podsumowanie | **high** (metoda) |
| FST Lisboa aeromap: **yaw** najbardziej wpływowy — **~16%** zmiany DF w badanym zakresie; roll **~9%** DF i **~12%** przesunięcia CoP; ride height **~10%** CD·A i **~20%** −CL·A między peakami | Técnico Lisboa / FST10e thesis abstract | **high** na ich aucie; **med** transfer |
| Chalmers CFS: kąty ekspansji **13°** vs **19°** — oba wysoki DF, wybrano **13°** dla **robustness** w manewrach; typowo ~**15°** jako start, zbyt stromy → separacja | Chalmers undertray thesis | **med–high** |
| GC min. **30 mm** static z kierowcą (T 2.2.1); zakaz sliding skirts / kontaktu z torem (T 2.2.2) | fs-rules-2026-t8 | **high** |
| Monash aero map: ground-effect wrażliwy na FRH/RRH/roll/steer/yaw — mapowanie postaw > jeden case @0° | Hendy / Monash 2019 | **high** (metoda) |

**Rada Spec (H2):** szukać **tylniejszego** docisku dyfuzora / uszczelnienia tyłu **bez obniżania nosa FW**. Gate przed zamrożeniem: **mapa Cx/Cz vs δ** (+ roll / RH jeśli budżet) i model toru Endurance. Nie optymalizować UT tylko pod δ=0 — Autocross to właśnie δ≠0.

---

## 3. H3 — odciążenie FW (ostatnia dźwignia balansu, nie pierwsza)

| Claim | Evidence | Confidence |
|---|---|---|
| Dokręcanie samego FW pcha balans na przód i utrudnia 50/50 | research-balance-shift; fizyka pakietu; Nagłowski: FW ~39% Fz | **high** |
| FW unload (kąt / elementy w dół) — tylko jeśli H1+H2 nie domykają ~12 pp | shortlista H3 w research-balance-shift | **high** jako kolejność Spec |
| Box FW: wysokość < **500 mm** przed HR; outboard przed osią < **250 mm**; envelope przy każdym setupie zawieszenia (T 8.2.1–4) | fs-rules-2026-t8 | **high** |
| Łatwo stracić \|Cz\| poniżej 3,682 przy odciążeniu przodu — mierzyć ΔCz równolegle z Δbalans | guardrail TARGETS | **high** (ryzyko) |

**Rada Spec (H3):** trzymać FW jako **stabilizator** Autocross (mniej yaw-sensitive niż UT — Staniszewski 2024), nie jako generator „brakujących Newtonów”. Odciążać dopiero z tabelą: ile pp balansu za ile |Cz|.

---

## 4. H4 — wąsy (TBD; nie baseline)

Z **Nagłowski 2024** (profil **Selig S1223** w ich serii — u nas **dobór profilu otwarty**):

| Wielkość | Baseline | Best iter111.4 |
|---|---:|---:|
| Cx | **1,453** | **1,480** |
| Cz | **−4,071** | **−4,100** |
| Balans przód | **60,3%** | **57,3%** |
| Cz/Cx | **−2,802** | **−2,770** |
| Fz_whiskers | — | **+12,9 N** (nośna!) |

Mechanizmy: blisko FW — wąs **kradnie** powietrze spod FW → cofa balans; nad wahaczem — chroni RW przed brudnym powietrzem; pozytywny wpływ też na UT. Same wąsy **nie** są generatorem docisku.

| Claim | Evidence | Confidence |
|---|---|---|
| Wąsy cofają balans o **kilka pp** przy lekkim koszcie L/D | Tab. 5.2: 60,3→57,3%; eff −2,802→−2,770 | **high** na ich aucie; **low–med** transfer na 017 |
| Nie automatycznie S1223 — dobrać profil pod lokalizację | decyzja Spec 2026-09-01 | **high** (proces) |
| Wchodzą **po** H1–H3, jeśli nadal za dużo z przodu | research-balance-shift H4 | **high** (kolejność) |

---

## 5. Co jest OUT / poza peak-DF

### 5.1 DRS ruchomy — OUT

- Jackson: open = −**35%** drag, ale DF spada mocno (CL 1,15→0,26).
- Własne `RW_iter019/020` (z research-balance-shift): Cx ↓ do **~0,83**, |Cz| ↓ do **~3,01** — **poniżej** kotwicy 3,682.
- **Wniosek:** DRS (nawet pasywne otwarcie) to narzędzie **prostych / oporu**, nie trzymania peak-DF ani domykania 12 pp balansu high-DF. Ruchomy = OUT; pasywny = osobna gałąź, nie ścieżka Spec peak.

### 5.2 Fan spod podłogi — OUT

- Michalecki: na profilowanej podłodze PM08 wentylator **psuje** |Cz| (~**30%+** gorzej vs baza Cz **−2,036**); żadna iteracja nie pobiła bazy.
- Legalnie T 11.11.1 ≤ **500 W** — ale decyzja osiągów = OUT (nie redesign pod ssanie).

---

## 6. Ograniczenia regulaminu i konstrukcji (nie „nice to have”)

| Limit | Treść | Impact na targety |
|---|---|---|
| T 8.2.1 | RW za HR: wysokość < **1,1 m**; FW < **500 mm**; outboard przed osią < **250 mm** | Max chord/span RW ograniczone boxem — 4-el. musi zmieścić się w **250 mm** za oponami (T 8.2.3) |
| T 8.2.2 | RW (>500 mm): nie outboard od most inboard **tylnej** opony | Wąski box szerokości — endplate/4-el. |
| T 8.2.4 | Envelope przy **any** suspension setup, z kierowcą i bez | Nie projektować „idealnego” RH tylko w CAD static |
| T 8.3.1–2 | **200 N** / ≥**225 cm²** → ugięcie ≤**10 mm**; **50 N** dowolny punkt → ≤**25 mm** | 4-el. + duże endplate = więcej powierzchni do ugięcia (Quintanas: tip endplate flex) |
| T 2.2.1 | GC ≥ **30 mm** static | Dyfuzor agresywny vs kontakt / T 2.2.2 skirts |
| T 11.11.1 | Active air movers ≤ **500 W** | Fan OUT i tak; cooling fans w limicie |

---

## 7. Endurance + Autocross — jak czytać trade-offy

| Event | Co wynika ze źródeł | Czego unikać |
|---|---|---|
| **Autocross** | Docisk w zakresie δ ważniejszy niż sam peak @0°; UT pomaga \|Cz\|, ale **traci** przy yaw — FW/RW stabilniejsze (Staniszewski 2024). Yaw może ruszyć DF o rząd **~16%** (FST Lisboa) | Optymalizacja UT tylko @ δ=0; „sztywny” dyfuzor bez mapy |
| **Endurance** | UT może **obniżyć** proxy energii (−**2,7%** F_ham mimo +~**10 kg**); trzeba modelu toru (udziały r). Bez DRS open — Cx ≲ 1,23 jest twardym limitem energii/prostych | Przenoszenie −2,7% na inny tor; dokładać masę aero bez proxy energii; fan |
| **Accel / długie proste** (niższy priorytet) | Jackson DRS −35% drag **niedostępne** jako aktywna ścieżka; pasywny low-AOA RW = świadomy trade \|Cz\| | Pogarszanie Cx 017 bez zwrotu w lap/energii |

**Praktyczna reguła Spec:** najpierw **tył (H1)** żeby zbliżyć CoP do 50/50 przy trzymanym |Cz|; potem **UT (H2)** pod DF+energię z gate yaw; FW (H3) tylko do domknięcia pp; wąsy (H4) jako polish.

---

## 8. Ostrzeżenia pakietowe (checklist przed zamrożeniem geometrii)

1. **Coupling 2D→3D:** optimum overlap/kątów z izolowanego RW **nie** przenosi się 1:1 (Staniszewski 2023: Cx/Cz na aucie prawie flat mimo dużego zysku 2D).
2. **Yaw/steer UT:** sam Cx@δ=0 **kłamie** przy mocnej podłodze — mapa δ przed freeze.
3. **Ride height / pitch:** ground effect i dyfuzor wrażliwe na FRH/RRH; GC **30 mm** + ugięcia T8.3 + bump = projektuj z marginesem, nie na styk.
4. **Sztywność T8.3:** zwłaszcza duże endplate i 4. element — ugięcie tipów zmienia skuteczny AOA w zakręcie.
5. **Nie mieszać modeli:** Nagłowski Cz≈−4,07 / Staniszewski pojazd Cz≈−2,03 / Jackson CL≈1,15 / **017 Cz=−3,682** — różne Aref/V/pakiety. Kierunki OK; liczby nie uśredniać.
6. **Nie inventować Aref** — Fluent Reference Values przed porównaniem OF.
7. **Wąsy:** Fz_whiskers > 0 — success metric = Δbalans / ΔRW / ΔUT, nie „siła na wąsie”.
8. **DRS/fan:** nie wracają jako „łatwy Cx” przy celu |Cz| ≥ 3,682.

---

## 9. Claims — tabela zbiorcza (do Spec)

| # | claim | evidence | confidence |
|---|---|---|---|
| C1 | Główne dźwignie cofania balansu = **RW + UT**, nie samo FW | Spec + research-balance-shift; Nagłowski udziały Fz; Staniszewski 2023/24 | **high** |
| C2 | Balans 017 ≈ **61,6%** przód; gap ≈ **12 pp** do 50/50 | Cm/Cz RW_iter017; zamrożenie 2026-09-01 | **high** roboczo; **med** vs pełny postpro Fluent CSV |
| C3 | Guardrail: \|Cz\| ≥ **3,682**, Cx ≲ **1,23** @ 15 m/s | TARGETS / CSV 017 | **high** |
| C4 | Optimum overlap RW ~**−30 mm** w 2D; na aucie wymaga re-check | Staniszewski 2023 Tab. 2D | **high** 2D; **med** 3D pakiet |
| C5 | Gap/overlap start McBeath **1–4%c / 1–6%c**; flaps ~25–30° / 30–70° | Jackson 2018 | **high** start |
| C6 | 4-el. RW = więcej parametrów setupu + potencjalnie więcej tyłu; koszt masa/sztywność/coupling | Quintanas 2023; Spec | **med** (zysk na 017 do zmierzenia) |
| C7 | Gurney ~**1–2%c** na ostatnich elementach = tani DF z tyłu | literatura Gurney + Quintanas setup | **med–high** |
| C8 | UT ~**1/3** Fz w pakiecie Nagłowskiego; pełny pakiet z UT wyższe \|Cz\| vs FW&RW dla każdego δ | Nagłowski Tab. 5.3; Staniszewski 2024 | **high** kierunek |
| C9 | UT yaw-sensitive; gate = mapa Cx/Cz(δ) + model toru (−**2,7%** F_ham proxy) | Staniszewski 2024; FST Lisboa ~**16%** DF vs yaw | **high** |
| C10 | Dyfuzor: start ~**13–15°** ekspansji, preferuj robustness nad max kątem | Chalmers 13° vs 19° | **med** |
| C11 | Wąsy: kilka pp balansu tył, lekki koszt L/D; same nośne; TBD po H1–H3 | Nagłowski 60,3→57,3% | **high** u nich; **low–med** transfer |
| C12 | Pasywne/open DRS obniża \|Cz\| poniżej 3,68 — nie ścieżka peak-DF | Jackson; RW_iter019/020 Cx~0,83 / \|Cz\|~3,01 | **high** |
| C13 | Fan OUT na profilowanej podłodze — psucie \|Cz\| ~30%+ vs baza PM08 | Michalecki | **high** |
| C14 | T8.3 + GC **30 mm** + box RW limitują agresję 4-el. / dyfuzora | FS Rules 2026 v1.1 | **high** |

---

## 10. Rekomendacje dla Spec (krótka shortlista)

1. **Kolejność prac:** H1 (RW, rozważyć 4-el. + gurney 1–2%c na TE) → H2 (UT/dyfuzor tylniejszy + mapa δ) → H3 (FW unload tylko do domknięcia pp) → H4 (wąsy, profil pod lokalizację).
2. **Każda iteracja raportuje:** Cx, Cz, Cm, **balans %** przy x=0,765 m — nie tylko „ładniejsze Cp”.
3. **4-el. RW:** tak jako kandydat setupu/peak tyłu; zamrozić dopiero po porównaniu z 3-el. na **tym samym** pakiecie 017 (coupling!).
4. **UT:** nie freeze bez Cx/Cz(δ); celuj w kąt ekspansji raczej **robust** (~13–15°) niż max theoretical; GC ≥ 30 mm z marginesem ugięć.
5. **FW:** nie dokręcać; odciążać świadomie z tabelą Δpp vs Δ|Cz|.
6. **DRS/fan:** zostają OUT względem peak-DF; pasywne klapy tylko jeśli kiedyś osobno liczycie energię prostych bez łamania |Cz|≥3,682.
7. **Walidacja:** CFD → symulacja toru → tor (nitki / flow-vis) — zgodnie z decyzją Spec; bez inventowanego Aref.

---

## Źródła (lokalne + web użyte w tej notatce)

**Lokalne KB:** `research-balance-shift.md`, `staniszewski-2023-wing.md`, `staniszewski-2024-energy.md`, `naglowski-2024-package.md`, `jackson-2018-cfd-drs.md`, `fs-rules-2026-t8.md`, `michalecki-fan-ground-effect.md`, `team-rwiter017-baseline.md`, `TARGETS.md`.

**Web (uzupełnienie multi-el. / gurney / yaw):**  
- Quintanas i Yani, *Design and manufacturing of a rear wing for Formula Student* (Dynamics UPC, 2023) — 4-el. RW, gurney, setup eventów.  
- McBeath guidelines via Jackson 2018 (gap/overlap/AOA).  
- Gurney: ICAS 2006; PMC4897339 (wysokość 1–2%c).  
- Yaw/aeromap: FST Lisboa aerodynamic mapping (~16% DF vs yaw).  
- Diffuser robustness: Chalmers CFS undertray (13° vs 19°).  
- LUTPUB Metropolia multi-element RW performance trade-offs (kierunek lap vs drag).

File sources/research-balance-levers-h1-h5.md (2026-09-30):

# Research: dźwignie balansu H1–H5 (Spec)

> **⚠️ 2027:** limity T8 w tej notatce (FW <500/<250 mm, UT „<500 mm”, RW „inboard tylnej opony”) to **2026 v1.1**. 2027: FW <350 mm przed LE przednich opon, środek auta poniżej góry opon, RW 700–1100 mm do zewnętrznej krawędzi tylnych opon — duża zmiana dla H1. Patrz [fs-rules-2027-t8.md](fs-rules-2027-t8.md).

**Status:** notatka robocza dla Spec (2026-09-01)  
**Język:** PL  
**Zasada:** wyłącznie KB w `sources/` (Staniszewski 2023/2024, Nagłowski 2024, Jackson 2018, Michalecki, T8/rules, research-balance-shift, research-fs-teams-practice, team-rwiter017 / Baseline002 kontekst). **Bez liczb spoza źródeł.**

**Kotwica** (`RW_iter017` @ **15 m/s**, zamrożone):

- Cx = **1,229**
- Cz = **−3,682**
- Cm = **−0,429**
- balans ≈ **61,6%** przód (z Cm/Cz)

**Cel:** maksymalny docisk, spokojny opór (Cx ≲ **1,23**), balans **48–52%** przód (ok. **12 pp** cofnięcia).

**Eventy:** Endurance + Autocross.

**Zamrożone:** DRS ruchomy **OUT**; fan **OUT**; wąsy **TBD**; rozważamy RW **4-el.** jako hipotezę CAD (w literaturze KB = **3** el.).

Powiązane: [research-balance-shift.md](research-balance-shift.md), [research-fs-teams-practice.md](research-fs-teams-practice.md), [fs-rules-2026-t8.md](fs-rules-2026-t8.md), [team-rwiter017-baseline.md](team-rwiter017-baseline.md).

Metryka CFD (Fluent / później OF): moment przy **x = 0,765 m**, Lref **1,53 m**, half-car, V=**15 m/s**. Guardrale sukcesu serii: **|Cz| ≥ 3,682**, **Cx ≲ 1,23**, Δbalans w stronę 50/50.

**Kolejność:** H1 → H2 → (H3 gdy trzeba) → H4 jeśli TBD=IN. **H5 = OUT** (nie ścieżka peak-DF).

---

## H1 — Więcej docisku z tylnego skrzydła (RW)

### Mechanizm

Chodzi o to, żeby **więcej docisku poszło z tyłu**: ustawiamy kąty / overlap / gap wieloelementowego RW w stronę optimum 2D ze Staniszewskiego 2023 — ale **na pakiecie** 017, nie na izolowanej kaskadzie. Montaż możliwie wysoko (Jackson: uniknąć disturbed flow za HR / roll hoop).

Opcjonalna pod-hipoteza CAD: **4 elementy** zamiast 3 (więcej powierzchni/slotów w envelope T8) — **bez** liczb ΔCz w ekstraktach.

### Oczekiwany kierunek (balans / DF / drag)

| Wielkość | Kierunek |
|---|---|
| Balans przód | **↓** (więcej tyłu → mniej % przodu) |
| \|Cz\| | **↑ lub =** (cel: nie poniżej 3,682) |
| Cx | **↑ ryzyko** — pilnować ≲ 1,23 |

### Evidence + confidence

| claim | evidence | confidence |
|---|---|---|
| Obniżenie kąta main + overlap ~−30 mm podnosi \|Fz\| 2D izolowanego RW (~398→~560–565 N) | Staniszewski 2023 Tab. 3/4 | **high** (2D) |
| Na pojeździe 3D Cx/Cz prawie stoją; coupling z body — nie wklejać 2D 1:1 | Staniszewski 2023 s. 32 + Wnioski | **high** (ostrzeżenie); efekt na 017 = **TBD** |
| RW closed = skok DF (Jackson CL_DF 1,15 / CD 1,21) | Jackson Results | **high** (kierunek); transfer V/A **low** |
| U Nagłowskiego RW ≈ **24%** Fz_all | Tab. 5.3 | **high** (ich auto); udział na 017 **TBD** |
| 4-el. RW: brak liczb w KB (Jackson/Staniszewski = 3 el.) | ekstrakty | **high** (brak danych); efekt = **hipoteza** |

### Ryzyka (T8, yaw)

- **T8:** RW >500 mm → wysokość **<1,1 m**; max **250 mm** za tylnymi oponami; nie outboard od most inboard tylnej opony (T 8.2.1–3); sztywność T 8.3; envelope przy any suspension (T 8.2.4).
- **4-el.:** więcej cięciwy/slotów łatwo wychodzi poza LE/TE limity i box szerokości endplate.
- **Yaw** (kąt jak w zakręcie): FW/RW „płaskie” vs δ względem UT (Staniszewski 2024) — H1 mniej yaw-wrażliwe niż H2, ale coupling body nadal.
- Stall / zbyt agresywne AOA (Jackson: stall ~25°; ich overall ~22,8°) — nie pchać „dla liczb”.

### Pierwszy eksperyment CFD

Na pakiecie **RWiter017** (nie izolowane 2D): seria 3–5 wariantów kątów/overlap/gap w stronę optimum Staniszewskiego (−main, overlap ~−30 mm jako orientacja, nie target). Mierzyć: Cx, Cz, Cm, **balans %** @ x=0,765 m. Guardrale: |Cz|≥3,682, Cx≲1,23.

**Osobno (później):** CAD 4-el. w T8 envelope → 1 case porównawczy vs 3-el. (bez obietnicy Δ z literatury).

### Kill criteria

- Δbalans **< ~2 pp** przy spełnionych guardralach **lub**
- Cx **> 1,23** przy |Cz| nielepzym od 3,682 **lub**
- stall / rozdział widoczny w Cp (jakościowo) bez zysku Fz tyłu **lub**
- 4-el.: nie mieści się w T8 / T 8.3 bez utraty |Cz| vs 3-el. → porzuć 4-el., zostań przy 3-el. + iteracja kątów.

---

## H2 — Mocniejszy / bardziej „tylny” dyfuzor–UT

### Mechanizm

Przyrost docisku z **podłogi / dyfuzora / uszczelnienia tyłu** — bez obniżania nosa FW. U Nagłowskiego UT ≈ **36%** Fz — duży kawałek, często tylny. Staniszewski 2024: pełny pakiet z UT&SW ma wyższe |Cz| dla każdego δ vs samo FW&RW; po modelu toru proxy energii **−2,7%** mimo **+~10 kg**.

### Oczekiwany kierunek (balans / DF / drag)

| Wielkość | Kierunek |
|---|---|
| Balans przód | **↓** (więcej Fz z tyłu UT) |
| \|Cz\| | **↑** (kierunek lit.) |
| Cx | **niejednoznaczny** — przy δ=0 często OK; przy 10–20° Cx pełnego pakietu bywa **wyższy** (Staniszewski 2024) |

### Evidence + confidence

| claim | evidence | confidence |
|---|---|---|
| UT ≈36% Fz_all u Nagłowskiego (Fz_ut ≈−202 N / −561 N) | Tab. 5.3 | **high** (ich auto); na 017 **TBD** |
| Pełny pakiet wyższe \|Cz\| dla każdego δ vs FW&RW | Staniszewski 2024 s. 54–55 | **high** (kierunek) |
| UT&SW yaw-sensitive; FW/RW mniej | Staniszewski 2024 s. 55–56 | **high** |
| Proxy energii −2,7% mimo +~10 kg (jeden tor) | s. 67–68 | **high** (F_ham); **med** (Wh) |

### Ryzyka (T8, yaw)

- **T8 / T2:** GC static ≥ **30 mm** (T 2.2.1); zakaz sliding skirts / kontaktu z torem (T 2.2.2); UT w boxie opon (T 8.2.2 <500 mm); envelope any setup (T 8.2.4). Niski UT = **wysokie** ryzyko Tech/dynamic rake.
- **Yaw (krytyczne przy Autocross+Endurance):** utrata Fz_UT przy δ≠0; Cx(δ) przecina się ~10° — **nie** zamrażać UT na samym δ=0.
- Masa (~+10 kg w szacunku Staniszewskiego) vs zwrot energii — wymaga modelu toru.

### Pierwszy eksperyment CFD

1 case: wzmocniony dyfuzor / uszczelnienie tyłu na bazie 017 (bez zmiany nosa FW). δ=**0°**: Cx, Cz, Cm, balans %. **Gate przed zamrożeniem:** mini-mapa Cx,Cz vs δ (przynajmniej 0° / ~5–10° / ~15°) + nota vs udziały toru (metoda Staniszewski 2024). GC w CAD ≥30 mm z marginesem.

### Kill criteria

- Przy δ=0: brak Δbalans ≥~2 pp **i** brak wzrostu |Cz| przy Cx≲1,23 **lub**
- Mapa δ: średni ważony |Cz| / F_ham **gorszy** niż baza na modelu toru Endurance **lub**
- GC / T 2.2.2 nie do utrzymania w any setup **lub**
- +kg bez zwrotu proxy energii → OUT geometrii / redukcja masy UT.

---

## H3 — Lekkie odciążenie przodu (FW w dół)

### Mechanizm

Zmniejszenie kąta / elementów FW (lub lokalne odciążenie), żeby zejść z front-bias — **tylko jeśli H1–H2 nie domykają ~12 pp**. Nie dokręcać FW „dla docisku” (pcha jeszcze bardziej na przód). U Nagłowskiego FW ≈ **39%** Fz — duża dźwignia w obie strony.

### Oczekiwany kierunek (balans / DF / drag)

| Wielkość | Kierunek |
|---|---|
| Balans przód | **↓** |
| \|Cz\| | **↓ ryzyko** (łatwo stracić peak DF) |
| Cx | **↓ lub ≈** (mniej AOA FW) |

### Evidence + confidence

| claim | evidence | confidence |
|---|---|---|
| Nie dokręcać samego FW jako pierwszej dźwigni cofania balansu | research-balance-shift; fizyka pakietu; Spec | **high** (kierunek) |
| FW ≈39% Fz u Nagłowskiego | Tab. 5.3 | **high** (ich auto) |
| FW box: <500 mm przed HR; <250 mm outboard przed osią; max 700 mm przed oponami | T 8.2.1–3 | **high** |

### Ryzyka (T8, yaw)

- **T8:** FW wysokość/outboard (T 8.2.1); keep-out kół (T 2.1.3); IA / attachment za AIP przy długim nosie (T 3.20).
- **Yaw:** FW mniej wrażliwe niż UT (Staniszewski 2024) — odciążenie FW jest „bezpieczniejsze” yawowo niż agresywny UT, ale kosztuje |Cz|.
- Utrata |Cz| poniżej 3,682 = fail celu Spec.

### Pierwszy eksperyment CFD

**Dopiero po** tabeli H1 (±H2). 1–2 warianty: −Δα FW / mniej agresywny element tylny FW na pakiecie po H1/H2. Guardrail twardy: |Cz| ≥ 3,682; cel balans 48–52%.

### Kill criteria

- |Cz| **< 3,682** przy jakimkolwiek kroku odciążenia **lub**
- Δbalans nieosiągalne bez łamania guardrala DF → wróć do H1/H2 (więcej tyłu), nie pogłębiaj H3 **lub**
- H1+H2 już w 48–52% → **nie uruchamiać** H3.

---

## H4 — Wąsy (profil TBD; lit. Selig S1223)

### Mechanizm

Generatory wirów / wąsy wpływają na przepływ wokół FW/RW/UT: u Nagłowskiego cofają balans o kilka pp (60,3%→**57,3%** best), wspierają RW/UT, same bywają **nośne** (Fz_whiskers > 0). Blisko FW kradną powietrze spod przedniego skrzydła. **U nas TBD** — nie automatycznie S1223; dobór profilu pod lokalizację.

### Oczekiwany kierunek (balans / DF / drag)

| Wielkość | Kierunek |
|---|---|
| Balans przód | **↓** kilka pp (Nagłowski) |
| \|Cz\| | **↑ lekko** lub ≈ (iter111.4: −4,071→−4,100) |
| Cx / L/D | **lekko gorzej** (efektywność −2,802→−2,770) |

### Evidence + confidence

| claim | evidence | confidence |
|---|---|---|
| Best wąsy: balans 57,3%, Cx 1,480, Cz −4,100 | Nagłowski Tab. 5.2 iter111.4 | **high** (ich auto) |
| Fz_whiskers > 0 (+5…+13 N) | Tab. 5.3 | **high** |
| Wspierają RW/UT, psują FW gdy blisko | s. 35 + Podsumowanie | **high** / interpretacja **med** |
| Transfer na 017 + inny profil | brak w KB | **low–med** |

### Ryzyka (T8, yaw)

- **T8 / T2.1.3:** wheel keep-out — **wysokie** ryzyko Scrutineering przy agresywnych wąsach (rules-aero-boxes-loopholes).
- Envelope <500 mm / szerokość opon; promienie krawędzi T 2.4.1.
- Yaw: brak mapy δ dla wąsów w KB — nieznana wrażliwość.
- Decyzja Spec = **TBD** — nie blokować H1/H2.

### Pierwszy eksperyment CFD

**Tylko jeśli** po H1–H3 nadal >~52% przód **i** Spec = IN. 1 lokalizacja + 1 profil (dobrany pod keep-out), porównanie vs baza po H1/H2: Δbalans, ΔCx, ΔCz, Fz komponentów. Nie kopiować ślepo S1223 / iter111.4.

### Kill criteria

- Spec zostaje **OUT** / TBD bez IN → nie CFD **lub**
- Δbalans <~2 pp przy koszcie L/D / Cx **lub**
- naruszenie T 2.1.3 / T 8.2 w any setup **lub**
- Fz_whiskers nośna bez netto zysku pakietu → OUT.

---

## H5 — Ruchomy DRS — **OUT** (ścieżka peak-DF zamknięta)

### Mechanizm

Regulowane elementy RW: closed = high DF + high drag; open = niski drag i **niższy** DF (Jackson). Własne pasywne `RW_iter019/020` na bazie 017: Cx↓ do ~**0,83**, |Cz|↓ do ~**3,01** — poniżej kotwicy 3,68. **Nie** narzędzie do trzymania peak DF ani do cofania front-bias przy high-DF.

### Oczekiwany kierunek (gdyby IN — tylko kontekst)

| Wielkość | Closed → Open |
|---|---|
| Balans | nie rozwiązuje „za dużo z przodu przy high-DF” |
| \|Cz\| | **↓** (Jackson; 019/020) |
| Cx | **↓** (Jackson −35% siły oporu; 019/020 Cx~0,83) |

### Evidence + confidence

| claim | evidence | confidence |
|---|---|---|
| Jackson closed CL_DF=1,15/CD=1,21; open 0,26/0,79 | Results | **high** |
| Pasywne 019/020: Cx~0,83, \|Cz\|~3,01 < 3,68 | research-balance-shift / CSV RW | **high** |
| DRS ruchomy **OUT** (Spec 2026-09-01); fan OUT (Michalecki) | INDEX / TARGETS | **high** (decyzja) |
| T8 cisza o movable aero — legalność ≠ decyzja Spec | fs-rules-2026-t8 | **high** (cisza); decyzja = Spec |

### Ryzyka (T8, yaw)

- Gdyby wrócić: T 2.2.2, T 8.2.4 (cały zakres ruchu w boxie), T 8.3 obu pozycji, T 9 CGS; Q&A/Scrutineering **M**.
- Priorytet Endurance+Autocross bez Accel-as-P1 → zysk prostych DRS mniej krytyczny niż peak DF + balans.
- Fan (pokrewny powered aero): Michalecki — na profilowanej podłodze |Cz| ~30%+ gorzej; decyzja OUT.

### Pierwszy eksperyment CFD

**Brak** w ścieżce Spec peak-DF. Ewentualna gałąź **pasywnego** low-AOA RW tylko jako osobny trade oporu (nie H5 ruchomy) — poza shortlistą balansu 12 pp.

### Kill criteria

- **Już zabite decyzją Spec (DRS ruchomy OUT).**
- Wznowienie tylko po jawnej zmianie Spec + Q&A; nawet wtedy: open |Cz| < 3,682 → nie jako narzędzie peak-DF / balans high-DF.

---

## Macierz skrótowa (dla Spec)

| # | Status | Pierwsza dźwignia? | Główne kill |
|---|---|---|---|
| **H1** RW | **IN — start** | tak | Cx>1,23 / brak Δbalans / stall; 4-el. poza T8 |
| **H2** UT | **IN — po/z gate yaw** | tak (2.) | gorszy F_ham na torze / GC / brak Δ |
| **H3** FW↓ | warunkowo | nie | \|Cz\|<3,682 |
| **H4** wąsy | **TBD** | nie | keep-out / brak Δ / Spec OUT |
| **H5** DRS | **OUT** | — | decyzja Spec |

**Fan:** OUT (Michalecki) — poza H1–H5; nie reanimować w tej shortliście.

---

## Claims zbiorcze

| claim | evidence | confidence |
|---|---|---|
| Gap 017 ≈ **12 pp** (61,6%→50%) | Cm/Cz + INDEX | **high** (roboczo) |
| Kolejność H1→H2→H3→H4; H5 OUT | research-balance-shift + Spec | **high** |
| 4-el. RW = hipoteza CAD bez liczb w KB | Jackson/Staniszewski = 3 el. | **high** (brak danych) |
| Przy Endurance+Autocross mapa δ = gate UT | Staniszewski 2024 | **high** (proces) |

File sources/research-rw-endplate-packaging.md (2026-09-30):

# Packaging endplate tylnego skrzydła (FS) — box, praktyka, Fluent H1 na RWiter017

> **⚠️ 2027:** sekcja 2 („RW inboard tylnej opony”) to **2026 v1.1**. W 2027 aero 700–1100 mm może sięgać do **zewnętrznej** krawędzi tylnych opon, a pas „góra tylnej opony – 700 mm” ma limit **150 mm inboard** od wewnętrznej krawędzi opony (T 8.2.2, T 2.1.3). Endplate pełnej szerokości nie schodzi poniżej 700 mm. Szczegóły: [fs-rules-2027-t8.md](fs-rules-2027-t8.md), [rules-2027-aero-loopholes.md](rules-2027-aero-loopholes.md).

**Status:** research 2026-09-07 (Europe/Warsaw)  
**Dla kogo:** Spec / CAD przed serią Fluent H1 na aucie (`RW_iter017`).  
**Zasada:** liczby tylko z cytowanych źródeł lokalnych. **Bez** wymyślania Cl/Cd dla RWiter017. **Bez** wpisywania Cl/Cd do `TARGETS.md`.  
**Kotwica zespołu (punkt odniesienia kampanii, nie wynik tej notatki):** Cx **1,229**, Cz **−3,682**, balans ≈ **61,6%** przód → ~**50/50**.

Powiązane: [fs-rules-2026-t8.md](fs-rules-2026-t8.md) · [jackson-2018-cfd-drs.md](jackson-2018-cfd-drs.md) · [checklist-h1-fluent-rw.md](checklist-h1-fluent-rw.md) · [SPEC-FLUENT-H1-RWITER017.md](../SPEC-FLUENT-H1-RWITER017.md) · [SPEC-H1-2D-GATE.md](../SPEC-H1-2D-GATE.md) · [sanity-cfd1-2d-rw-vs-lit.md](sanity-cfd1-2d-rw-vs-lit.md).

---

## 1. Po co ta notatka

Endplate domyka rozpiętość RW, tnie przeciek tipowy i ustawia, jak wir tip oraz ślad za autem wchodzą w RW i wake opon / dyfuzora. Packaging musi najpierw zmieścić się w envelope **T 8**, potem dać sensowny flow na aucie we Fluencie H1. To notatka **packagingowa** — nie karta Cl.

---

## 2. Cue regulaminowe (FS Rules 2026 v1.1 — T 8)

Źródło lokalne: [fs-rules-2026-t8.md](fs-rules-2026-t8.md) (PDF `team/rules-current.pdf`).

Dla **wysokiego RW / endplate** (aero za head restraint, zwykle wysokość **> 500 mm** od ziemi):

- szerokość: **nie outboard** od most inboard point tylnej opony/koła (T 8.2.2) — RW >500 mm siedzi **inboard** tylnej opony;
- wysokość aero za HR: **niższa niż 1,1 m** od ziemi (T 8.2.1; Fig. 14: 1100 mm);
- setback do tyłu: max **250 mm** za rearmost part of the rear tires (T 8.2.3);
- envelope przy kołach prosto i **any suspension setup**, z kierowcą i bez (T 8.2.4).

Implikacja: nasze RW jest w **wąskim** boxie szerokości (inboard tylnej opony), pod limitem **1,1 m**, z max **250 mm** za oponami.

---

## 3. 800×500 mm — to skrzynka meshu OF 2D, **nie** T 8

**Nie mylić:**

| Co | Skąd | Znaczenie |
|----|---|---|
| Envelope T 8 | [fs-rules-2026-t8.md](fs-rules-2026-t8.md) | płaszczyzny względem opon / HR / ziemi — **nie** prostokąt 800×500 |
| Skrzynka **800×500 mm** | [SPEC-H1-2D-GATE.md](../SPEC-H1-2D-GATE.md) („skrzynka 800×500”); [sanity-cfd1-2d-rw-vs-lit.md](sanity-cfd1-2d-rw-vs-lit.md) („domena endplate 800×500 mm”) | **domena / mesh box OpenFOAM 2D**, izolowane skrzydło — **nie** limit regulaminowy endplate |

Claim T 8: box **800×500 mm** jako envelope endplate/wing **nie występuje** w FS Rules 2026 v1.1. Jeśli ktoś pamięta 800×500 z FSAE / starszych lat — **nie przenosić** na CAD 2026. Przy Fluent H1 na aucie obowiązuje envelope T 8, nie skrzynka OF 2D.

---

## 4. Jackson 2018 — ich auto (ostrzeżenie T 8 2026)

Źródło lokalne: [jackson-2018-cfd-drs.md](jackson-2018-cfd-drs.md).

Na **ich** aucie (paper, nie nasz envelope):

- góra endplate **1200 mm** od ziemi;
- tylna ściana endplate **250 mm** za tylnymi kołami;
- wniosek: montować RW **jak najwyżej**, żeby uniknąć disturbed flow / wake za głową kierowcy / roll hoop / air intake.

**Ostrzeżenie 2026:** T 8.2.1 wymaga wysokości **&lt; 1,1 m**. Wartość **1200 mm** z Jacksona to **ich** car / ówczesny envelope — **przekracza** limit T 8 2026. Nie kopiować jako legalny target CAD. Setback **250 mm** zgadza się z T 8.2.3 (max 250 mm za tylnymi oponami). U nas „jak najwyżej” kończy się **pod 1,1 m**, nie na 1200 mm.

CL/CD / AOA Jacksona opisują **ich** RW + DRS — **nie** przenosić na kartę RWiter017 ani do `TARGETS.md`.

---

## 5. Fluent H1 na RWiter017 — endplate zamrożony, potem tipy

Kampania: [SPEC-FLUENT-H1-RWITER017.md](../SPEC-FLUENT-H1-RWITER017.md) · kolejność: [checklist-h1-fluent-rw.md](checklist-h1-fluent-rw.md).

**Proces packaging / endplate w H1:**

1. **Zamrozić endplate** (wysokość / setback / obrys w limicie T 8) na czas serii **3-elementowej**: kąty → overlap → gap (jeden parametr naraz).
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

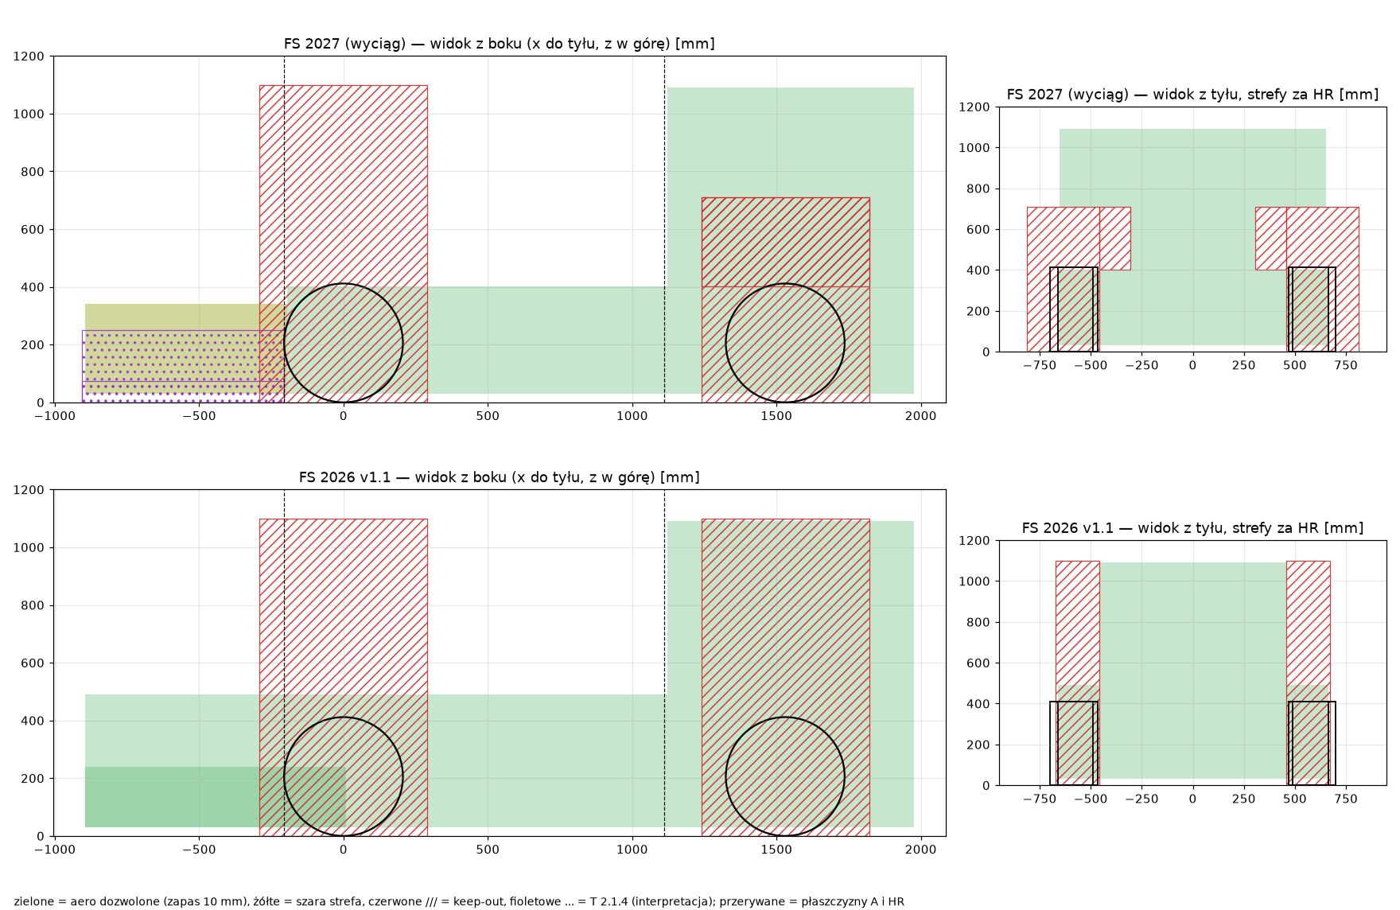
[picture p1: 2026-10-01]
team/cad-boxes/out/preview.png

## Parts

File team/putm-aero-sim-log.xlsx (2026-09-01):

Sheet: FW
Nazwa | Osoba | Opis | Hipoteza | Wniosek | Data | Model Bazowy | Gotowe? | Cm | Cx | Cz | Mdot_Radiator | Zdjęcie 1 | Zdjęcie 2 | Zdjęcie 3 | Efektywność | Balans | Powierzchnia Czołowa | Siła docisku | CoP | CoP % Front
FWiter001 | Mikołaj Wojnowski | iter078 z dodaną lotką obok koła |  |  | 2025-10-22 | iter078 | Done | -0.154 | 1.261 | -3.514 | -0.108 |  |  |  | -2.787 |  |  | 0 | -0.07 | -0.04
FWiter002 | Mikołaj Wojnowski | FWiter001 bez chłodnic |  |  | 2025-10-22 | FWiter001 | Done | -0.173 | 1.281 | -3.636 | - | https://drive.google.com/file/d/1nprH8967gYnoiLQdmdUTJAkbU-zIQlkt/view?usp=sharing |  |  | -2.837 |  |  | 0 | -0.07 | -0.05
FWiter003 | Mikołaj Wojnowski | FWiter001 z uproszczonymi kołami |  |  | 2025-10-23 | FWiter001 | Done | -0.151 | 1.263 | -3.516 | -0.107 |  |  |  | -2.784 |  |  | 0 | -0.07 | -0.04
FWiter004 | Mikołaj Wojnowski | FWiter003 bez chłodnic |  |  | 2025-10-23 | FWiter003 | In progress | -0.161 | 1.279 | -3.611 | - | https://drive.google.com/file/d/1nprH8967gYnoiLQdmdUTJAkbU-zIQlkt/view?usp=sharing | https://drive.google.com/file/d/1nprH8967gYnoiLQdmdUTJAkbU-zIQlkt/view?usp=sharing | https://drive.google.com/file/d/1nprH8967gYnoiLQdmdUTJAkbU-zIQlkt/view?usp=sharing | -2.824 |  |  | 0 | -0.07 | -0.04
FWiter005 | Mikołaj Wojnowski | FWiter003 z dzielnikiem |  |  | 2025-10-31 | FWiter003 | In progress | -0.271 | 1.240 | -3.515 | -0.104 |  |  |  | -2.835 |  |  | 0 | -0.12 | -0.08
FWiter006 | Mikołaj Wojnowski | FWiter003 z płaskim głównym profilem |  |  | 2025-10-31 | FWiter003 | In progress | -0.303 | 1.234 | -3.523 | -0.104 |  |  |  | -2.856 |  |  | 0 | -0.13 | -0.09 | jebac disa
FWiter007 | Mikołaj Wojnowski | FWiter003 z nową podłogą i chłodnicami |  |  | 2025-11-01 | FWiter003 | In progress |  |  |  |  |  |  |  | #DIV/0! |  |  | 0 | #DIV/0! | #DIV/0!
FWiter008 | Mikołaj Wojnowski | FWiter005 i FWiter006 połączone |  |  | 2025-11-01 |  | In progress | -0.303 | 1.241 | -3.517 | -0.102 |  |  |  | -2.834 |  |  | 0 | -0.13 | -0.09
FWiter009 | Mikołaj Wojnowski | FWiter007 bez chłodnic |  |  | 2025-11-01 | FWiter007 | In progress |  |  |  |  |  |  |  | #DIV/0! |  |  | 0 | #DIV/0! | #DIV/0!
FWiter010 | Mikołaj Wojnowski | FWiter006 z jednym profilem |  |  | 2025-11-09 | FWiter006 | In progress | -0.111 | 1.218 | -3.427 | 0.106 |  |  |  | -2.813 |  |  | 0 | -0.05 | -0.03
FWiter011 | Mikołaj Wojnowski | FWiter006 z nowym endplate |  |  | 2025-11-18 | FWiter006 | In progress | -0.449 | 1.216 | -3.811 | 0.106 |  |  |  | -3.135 |  |  | 0 | -0.18 | -0.12
FWiter012 | Mikołaj Wojnowski | FWiter011 z wyższym endplate do maksimum regulacji 2027 |  |  | FWiter011 | 2025-11-19 | In progress | -0.441 | 1.219 | 3.700 | 0.104 |  |  |  | 3.035 |  |  | 0 | 0.18 | 0.12
FWiter013 | Mikołaj Wojnowski | FWiter011 z wyższym endplate o 20mm i innym kształtem |  |  | FWiter011 | 2025-11-20 | In progress | -0.438 | 1.212 | 3.721 | 0.095 |  |  |  | 3.071 |  |  | 0 | 0.18 | 0.12
FWiter014 | Mikołaj Wojnowski | FWiter011 z nowym endplate, ma kształt airfoila |  |  | FWiter011 | 2025-11-23 | In progress | -0.458 | 1.217 | -3.787 | -0.105 |  |  |  | -3.111 |  |  | 0 | -0.18 | -0.12
FWiter015 | Łukasz Frątczak | FWiter011, zmniejszony kąt natarcia o 25 stopni od strony wewnętrznej |  |  | FWiter003 | 2025-11-24 | In progress | -0.176 | 1.225 | 3.573 | 0.099 |  |  |  | 2.917 |  |  | 0 | #VALUE! | #VALUE!
FWiter016 | Mikołaj Wojnowski | FWiter011 z nowym middleplate |  |  | FWiter011 | 2025-11-29 | In progress | -0.482 | 1.209 | 3.764 | 0.104 |  |  |  | 3.112 |  |  | 0 | 0.20 | 0.13
FWiter017 | Mikołaj Wojnowski | FWiter011 z dodatkowymi lotkami na endplate |  |  | FWiter011 | 2025-11-29 | In progress | -0.502 | 1.250 | -3.865 | 0.107 |  |  |  | -3.091 |  |  | 0 | -0.20 | -0.13
FWiter018 | Łukasz Frątczak | FWiter011 z nowa wysokością, wąsem oraz profilami po stronie zewnetrznej |  |  | FWiter011 | 2025-12-17 | In progress | -0.104 | 1.220 | 3.415 | 0.100 |  |  |  | 2.799 |  |  | 0 | #VALUE! | #VALUE!
FWiter019 | Łukasz Frątczak | FWiter018 z lepszymi profilam zewnętrznymi |  |  | FWiter011 | 2025-12-18 | In progress | -0.134 | 1.234 | 3.467 | 0.103 |  |  |  | 2.810 |  |  | 0 | #VALUE! | #VALUE!
FWiter020 | Łukasz Frątczak | FWiter019 z grillem w dzielniku oraz nowym profilem lotniczym |  |  | FWiter011 | 2025-12-20 | In progress | -0.243 | 1.247 | 3.563 | 0.104 |  |  |  | 2.857 |  |  | 0 | #VALUE! | #VALUE!
FWiter021 | Piotr Polus | FWiter011 z lotkami na endplate i dodatkowym, górnym profilem |  |  | 2025-12-26 | FWiter011 | Cancelled |  |  |  |  |  |  |  | #DIV/0! |  |  | 0 | #DIV/0! | #DIV/0!
FWiter022 | Piotr Polus | FWiter021 z łagodniejszym łukiem endplate |  |  | 2026-01-06 | FWiter011 | Cancelled |  |  |  |  |  |  |  | #DIV/0! |  |  | 0 | #DIV/0! | #DIV/0!
FWiter023 | Piotr Polus | FWiter021 z wydłużonym i poszerzonym górnym profilem | Wzniesienie większej ilości powietrza nad oponą, większy docisk z zachowanym w miarę gładkim przepływem dla podłogi | Model ma potencjał, przetestować z profilem głównym na 2027 i nową podłogą | 2026-01-13 | FWiter011 | Done | -0.451 | 1.249 | 3.753 | -0.107 |  |  |  | #VALUE! |  |  | #VALUE! | #VALUE! | #VALUE!
FWiter024 | Łukasz Frątczak | FWiter024 (nowy workflow) |  |  | FWiter011 |  | In progress | -0.376 | 1.239 | 3.716 | -0.111 |  |  |  | 2.999 |  |  |  | #VALUE! | #VALUE!
FWiter024 | Łukasz Frątczak | Koncepcja pod aero 27 wariant 4 + prototyp mocowania nowego od dolu |  |  | FWiter011 | 2026-01-17 | In progress | -0.381 | 1.245 | 3.761 | 0.109 |  |  |  | 3.021 |  |  | 0 | #VALUE! | #VALUE!
FWiter025 | Łukasz Frątczak | Koncpecja pod aero 27 wariant 1 (nowy workflow) |  |  | FWoter011 | 2026-01-27 | In progress | -0.185 | 1.259 | 3.646 | -0.108 |  |  |  | 2.896 |  |  | 0 | 0.08 | 0.05
FWiter026 | Łukasz Frątczak | FWiter025 z lekko wiekszym mp oraz lotkami na ednplate |  |  | FWiter011 | 2026-02-03 | In progress | -0.153 | 1.282 | 3.671 | -0.108 |  |  |  | 2.863 |  |  | 0 | #VALUE! | #VALUE!
FWiter027 | Łukasz Frątczak | FW026 ze zmieniona wiezyczka od dolu ,profilem laminarmym na endplate oraz wiekszym MP w srodkowej czesci |  |  | FWiter011 | 2026-02-07 | In progress | -0.167 | 1.264 | 3.660 | -0.108 |  |  |  | 2.896 |  | 0.5297069 | 534.3616994 | #VALUE! | #VALUE!
FWiter028 | Łukasz Frątczak | FWiter026 z lotkami na ednplate wyzej oraz dodatkowym profilem nad mp |  |  | FWiter011 | 2026-02-08 | In progress | -0.262 | 1.284 | 3.702 | 0.107 |  |  |  | 2.883 |  | 0.5296984 | 540.4850458 | #VALUE! | #VALUE!
FWiter029 | Łukasz Frątczak | FWiter028 z innym umiejscowieniem lotek |  |  | FWiter011 | 2026-02-19 | In progress | -0.231 | 1.278 | 3.666 | 0.107 |  |  |  | 2.869 |  |  | 0 | #VALUE! | #VALUE!
FWiter030 | Łukasz Frątczak | FWiter028+029 |  |  | FWiter011 | 2026-02-19 | In progress | -0.238 | 1.303 | -3.686 | -0.109 |  |  |  | -2.829 |  | 0.5297009 | -538.1516157 | #VALUE! | #VALUE!
FWiter031 | Łukasz Frątczak | FWiter030 z zagieciem na endplacie oraz lzejszym zagieciem |  |  | FWiter011 | 2026-02-19 | In progress | -0.224 | 1.285 | 3.682 | -0.107 |  |  |  | 2.865 |  |  | 0 | #VALUE! | #VALUE!
FWiter032 | Łukasz Frątczak | FWiter031 z wyciagnieciem "rynny" |  |  | FWiter011 | 2026-02-19 | In progress | -0.225 | 1.287 | 3.691 | 0.107 |  |  |  | 2.868 |  |  | 0 | #VALUE! | #VALUE!
FWiter033 | Łukasz Frątczak | FWiter032 z wieksza srednica rynny |  |  | 2026-02-22 | FWiter011 | In progress | -0.236 | 1.281 | -3.666 | -0.110 |  | v |  | -2.862 |  |  | 0 | #VALUE! | #VALUE!
FWiter034 | Łukasz Frątczak | FWiter032 z podniesieniem rynny pod koniec endplate-a |  |  | 2026-02-23 | FWiter011 | In progress | -0.230 | 1.274 | 3.650 | -0.107 |  |  |  | 2.865 |  |  | 0 | #VALUE! | #VALUE!
FWiter035 | Łukasz Frątczak | FWier032 z profilami na lotce przedniej |  |  | 2026-02-24 | FWiter011 | In progress | -0.217 | 1.289 | 3.690 | 0.107 |  |  |  | 2.863 |  |  | 0 | #VALUE! | #VALUE!
FWiter036 | Łukasz Frątczak | FWiter035 bez wygiętego mp |  |  | 2026-02-24 | FWiter011 | In progress | -0.145 | 1.272 | 3.578 | 0.106 |  |  |  | 2.813 |  |  | 0 | #VALUE! | #VALUE!
FWiter037 | Łukasz Frątczak | FWiter035 z wyciagnietymi lotkami |  |  | 2026-02-25 | FWiter011 | In progress | -0.291 | 1.273 | 3.722 | 0.103 |  |  |  | 2.924 |  |  | 0 | #VALUE! | #VALUE!
FWiter038 | Łukasz Frątczak | FWiter037 poprawiony pod wzgledem zapasu endplate-u ( 7mm z dolu i 7 z gory) |  |  | 2026-03-29 | FWiter011 | Done | -0.260 | 1.288 | 3.718 | 0.105 |  |  |  | 2.887 |  |  | 0 | #VALUE! | #VALUE!
FWiter039 | Łukasz Frątczak | FWiter038 z trzema lotkami | zwiekszenie aspect ratio plus dodanie kolejnej lotki zwiekszy Cz |  | 2026-03-31 | Fwiter011 | Done | -0.436 | 1.294 | 3.821 | -0.107 |  |  |  | 2.953 |  |  | 0 | #VALUE! | #VALUE!
FWiter040 | Łukasz Frątczak | FWiter039 z mniejszymi lotkami na endplacie oraz wieksza iloscia VG | zwiekszenie turbulencji przy endplacie w celu zmniejszenia vrtexow przed przednimi kolami oraz uzycie profili z lotek w celu oszczednosci | mniejsze lotki sa gorsze | 2026-04-02 | Fwiter011 | In progress | -0.444 | 1.288 | 3.799 | -0.111 |  |  |  | 2.950 |  |  | 0 | #VALUE! | #VALUE!
FWiter041 | Piotr Polus | Endplate z FWiter022 z przelotem | zmniejszenie ciśnienia pod profilami 2 i 3 przez ujście powietrza na zewnątrz | zły kąt i za mały prześwit wlotu dla przepływu powietrza, słaby docisk | 2026-03-31 | FWiter011 | Done | -0.581 | 1.212 | 3.627 | 0.109 |  |  |  | #VALUE! |  |  | #VALUE! | #VALUE! | #VALUE!
FWiter042 | Łukasz Frątczak | Fwiter039 ale z profilami na endplacie z gornej lotki (nadal mniejsze ale juz o tylko 25%) oraz wieksza ich ilosc oraz trojkatne VGs | to samo co w 040 | minimalnie udalo sie zniwelowac turbulencje przed przednim kolem ale Cz spadl, mozliwe zmiany to zwiekszenie lotek znowu oraz inne polozenie | 2026-04-04 | FWiter011 | In progress | -0.426 | 1.300 | 3.803 | 0.110 |  |  |  | 2.925 |  |  | 0 | #VALUE! | #VALUE!
FWiter043 | Łukasz Frątczak | FWiter039 z wieksza gorna lotka oraz inna geometria na endplate | dalsza walka z vortexami | WOW | 2026-02-09 | FWiter011 | In progress | -0.480 | 1.308 | 3.866 | 0.110 |  |  |  | 2.956 |  |  | 0 | #VALUE! | #VALUE!
FWiter044 | Piotr Polus | Test skrzydła z iter023 z nowym pakietem | baseline dla nowych wersji |  | 2025-05-06 | FWiter023 | Done | -0.643 | 1.245 | 3.792 | -0.108 |  |  |  | 3.046 |  |  | 0 | 0.26 | 0.17
FWiter045 | Piotr Polus | Skrzydło FWiter023 na pierwszej wersji nowego mocowania | Sprawdzenie przepływu wokół kratownicy |  | 2026-05-16 | FWiter044 | Done | -0.687 | 1.233 | 3.665 | -0.112 |  |  |  | #VALUE! |  |  | #VALUE! | #VALUE! | #VALUE!
FWiter046 | Łukasz Frątczak | FWiter043 z Prototypem/ placeholder na mocowanie z boku |  | skurwysynstwo nie chce sie liczyc w cfd |  |  | Cancelled |  |  |  |  |  |  |  | #DIV/0! |  |  | 0 | #DIV/0! | #DIV/0!
FWiter047 | Mikołaj Wojnowski | FWiter043 z nowym RW i UT |  | cwel | 2026-04-15 | FWiter043 / Baseline 2 | In progress | -0.684 | 1.282 | -3.758 | 0.113 |  |  |  | -2.932 |  |  | 0 | -0.28 | -0.18
FWiter048 | Piotr Polus | Nowy główny profil na 27 | Voidboxy inspirowane przeciekami o regulacjach na '27 | wyniki nie są złe ale nie było mocowania więc to oszustwo |  | FWiter045 | Done | -0.695 | 1.251 | 3.782 | 0.109 |  |  |  | #VALUE! |  |  | #VALUE!
FWiter049 | Łukasz Frątczak | FWiter043 z wyciecien w endplate oraz stala geometria MP | lepsza efektywnosc w zakretach |  | 2026-04-25 |  | Done | -0.310 | 1.279 | 3.573 | 0.109 |  |  |  | #VALUE! |  |  | #VALUE!
FWiter050 | Piotr Polus | Stara symulka z marca: stary profil główny i mocowanie, nowa podłoga, endplate i lotki z FWiter022 | eksperymenty z lotkami | Lepszy Cz niż w iter023 oznacza, że używane przeze mnie dotychczas dodatkowe profile zmniejszają efektywność profili 1 i 2 | 2026-03-08 | FWiter022 | Done | -0.689 | 1.212 | 3.795 | -0.108 |  |  |  | #VALUE! |  |  | #VALUE!
FWiter051 | Piotr Polus | Skręcone profile 1 i 2, o 15° mniejszy kąt natarcia nad voidami, usunięte dodatkowe profile | Voidy pod głównym profilem wraz z profilami 1 i 2 o mniejszym kącie natarcia mają powodować mniejsze wzbijanie powietrza, przepuszczając go więcej na podłogę | Mimo zmniejszenia kąta profili docisk jest większy, więc możliwe że zmiana spełnia swój cel | 2026-08-26 | FWiter048 | Done | -0.671 | 1.321 | 3.806 | -0.113 |  |  |  | #VALUE! |  |  | #VALUE!
FWiter052 | Łukasz Frątczak | Wywrwanie spod zawiechy najwieksze jak sie da oraz skosne skrzydlo |  | slabe | 2026-05-10 |  | In progress | -0.505 | 1.198 | 3.328 | -0.110 |  |  |  | #REF! |  |  | #REF!
FWiter054 | Mikołaj Wojnowski | Nowy koncept endplate | Lepszy przepływ powietrza w zakręcie, seksowniejszy endplate zgodnie z zaleceniem rabina | Kiepski przepływ, ten pomysł tak jak i FWiter013 nie są dobre przynajmniej w symulacjach na wprost | 2026-05-18 |  | In progress |  |  |  |  |  |  |  | #DIV/0! |  |  | 0
FWiter055 | Mikołaj Wojnowski | Nowy koncept endplate | Lepszy przepływ powietrza w zakręcie, seksowniejszy endplate zgodnie z zaleceniem rabina |  |  |  | In progress |  |  |  |  |  |  |  | #DIV/0! |  |  | 0
FWiter056 | Piotr Polus | Nowy, wygładzony profil główny z profilami 1 i 2 z 051 | Wytrzymalsza, lepsza aerodynamicznie, wykonawczo (i wizualnie) geometria |  |  |  | In progress |  |  |  |  |  |  |  | #DIV/0! |  |  | 0
FWiter057 | Piotr Polus | Wygładzone załamania profili 1 i 2 z 048 i nowy profil główny | Porównanie profili 1 i 2 z 048 i 051 na nowym profilu głównym |  |  |  | In progress |  |  |  |  |  |  |  | #DIV/0! |  |  | 0
FWiter058 | Przemek Iwan | Testowanie nowej koncepcji FW, do testów przepływu pod nim i działaniem kaskady | Skrzydło zajebane od green team bedzie dzialac, na dole regulaminowa dziura i podwojne lotki |  |  |  | In progress |  |  |  |  |  |  |  | #DIV/0! |  |  | 0
FWiter059 | Przemek Iwan | Poprzednia koncepcja tylko z dodatkowa lotka wczesniej | Dodana kolejna lotka wyjebie powietrze ponad koło = mniejszy opor w wiekszy docisk, plus jest dosyc wysoko wiec nie powinno afektowac az tak dzialania skrzydla |  |  |  | In progress |  |  |  |  |  |  |  | #DIV/0! |  |  | 0
FWiter060 | Olek Wasiluk | REDESIGN na profilu głównym z poprzednich iteracji, optymalizacja layoutu w oparciu o symulki 2D |  |  |  |  | In progress |  |  |  |  |  |  |  | #DIV/0! |  |  | 0
FWiter061 |  |  |  |  |  |  | In progress |  |  |  |  |  |  |  | #DIV/0! |  |  | 0
FWiter062 |  |  |  |  |  |  | In progress |  |  |  |  |  |  |  | #DIV/0! |  |  | 0
FWiter063 |  |  |  |  |  |  | In progress |  |  |  |  |  |  |  | #DIV/0! |  |  | 0
FWiter064 |  |  |  |  |  |  | In progress |  |  |  |  |  |  |  | #DIV/0! |  |  | 0
FWiter065 |  |  |  |  |  |  | In progress |  |  |  |  |  |  |  | #DIV/0! |  |  | 0
FWiter066 |  |  |  |  |  |  | In progress |  |  |  |  |  |  |  | #DIV/0! |  |  | 0
FWiter067 |  | 67 |  |  | 67 | 67 | In progress | 67 | 67 | 67 | 67 | 67 | 67 | 67 | 67 | 67 | 67 | 1237280.625 | 67.00 | 67.00 | 67 | 67 | 67 | 67 | 67 | 67 | 67 | 67
 |  |  |  |  |  |  | In progress |  |  |  |  |  |  |  | #DIV/0! |  |  | 0
 |  |  |  |  |  |  | In progress |  |  |  |  |  |  |  | #DIV/0! |  |  | 0
 |  |  |  |  |  |  | In progress |  |  |  |  |  |  |  | #DIV/0! |  |  | 0
 |  |  |  |  |  |  | In progress |  |  |  |  |  |  |  | #DIV/0! |  |  | 0
 |  |  |  |  |  |  |  |  |  |  |  |  |  |  | #DIV/0! |  |  | 0
 |  |  |  |  |  |  |  |  |  |  |  |  |  |  | #DIV/0! |  |  | 0
 |  |  |  |  |  |  |  |  |  |  |  |  |  |  | #DIV/0! |  |  | 0
 |  |  |  |  |  |  |  |  |  |  |  |  |  |  | #DIV/0! |  |  | 0
 |  |  |  |  |  |  |  |  |  |  |  |  |  |  | #DIV/0! |  |  | 0
 |  |  |  |  |  |  |  |  |  |  |  |  |  |  | #DIV/0! |  |  | 0
 |  |  |  |  |  |  |  |  |  |  |  |  |  |  | #DIV/0! |  |  | 0
 |  |  |  |  |  |  |  |  |  |  |  |  |  |  | #DIV/0! |  |  | 0
 |  |  |  |  |  |  |  |  |  |  |  |  |  |  | #DIV/0! |  |  | 0
 |  |  |  |  |  |  |  |  |  |  |  |  |  |  | #DIV/0! |  |  | 0
 |  |  |  |  |  |  |  |  |  |  |  |  |  |  | #DIV/0! |  |  | 0
 |  |  |  |  |  |  |  |  |  |  |  |  |  |  | #DIV/0! |  |  | 0
 |  |  |  |  |  |  |  |  |  |  |  |  |  |  | #DIV/0! |  |  | 0
 |  |  |  |  |  |  |  |  |  |  |  |  |  |  | #DIV/0! |  |  | 0
 |  |  |  |  |  |  |  |  |  |  |  |  |  |  | #DIV/0!
 |  |  |  |  |  |  |  |  |  |  |  |  |  |  | #DIV/0!
 |  |  |  |  |  |  |  |  |  |  |  |  |  |  | #DIV/0!
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

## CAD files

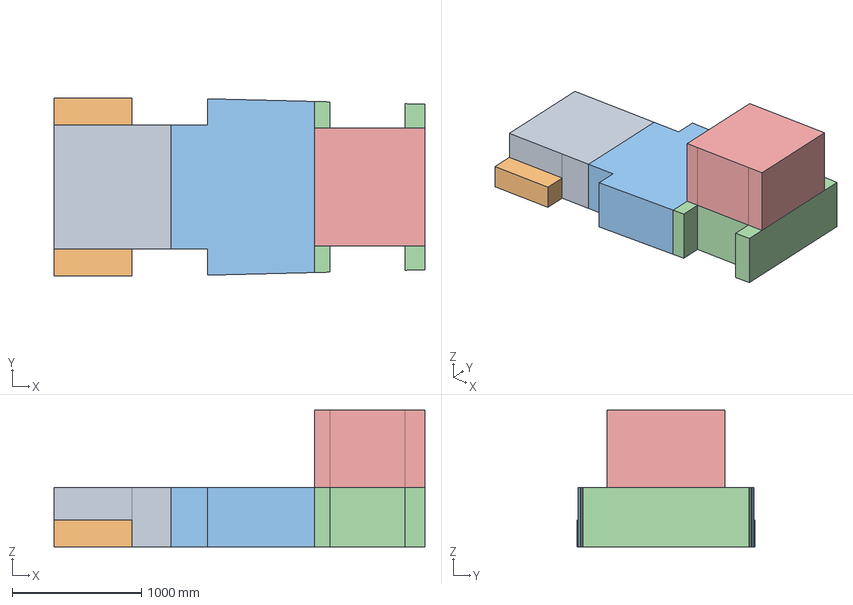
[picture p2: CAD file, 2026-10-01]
team/cad-boxes/out/fs2026_dozwolone_full.step
2871.5 x 1380.0 x 1060.0 mm
OK_2026_przod_srodek_ponizej_500
OK_2026_przod_outboard_ponizej_250
OK_2026_srodek_ponizej_500
OK_2026_tyl_ponizej_500
OK_2026_tyl_500-1100_inboard_opony

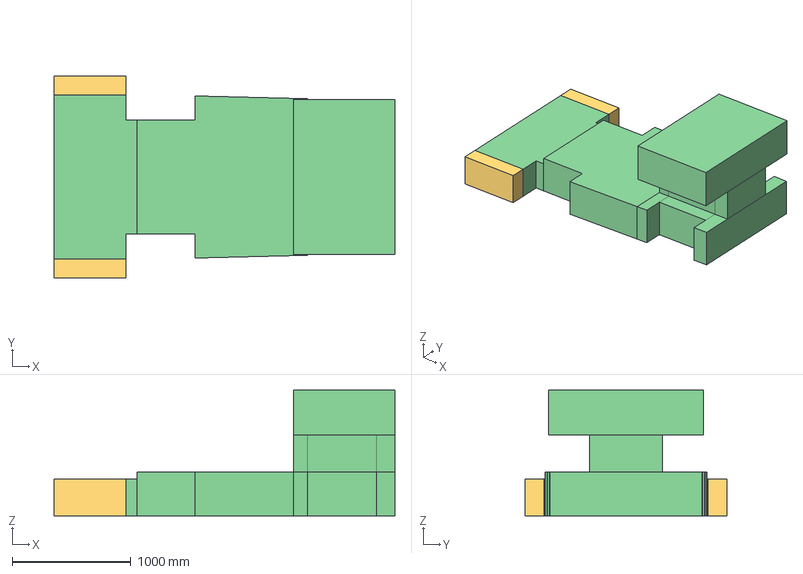
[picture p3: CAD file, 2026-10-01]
team/cad-boxes/out/fs2027_dozwolone_full.step
2871.5 x 1700.0 x 1060.0 mm
OK_2027_przod_ponizej_350
SZARA_2027_przod_outboard_bez_limitu_szer_T822
OK_2027_srodek_ponizej_gory_opon
OK_2027_tyl_nisko_pelna_szer
OK_2027_tyl_pas_gora_opony-700_inboard150
OK_2027_tyl_700-1100_do_zewn_opony

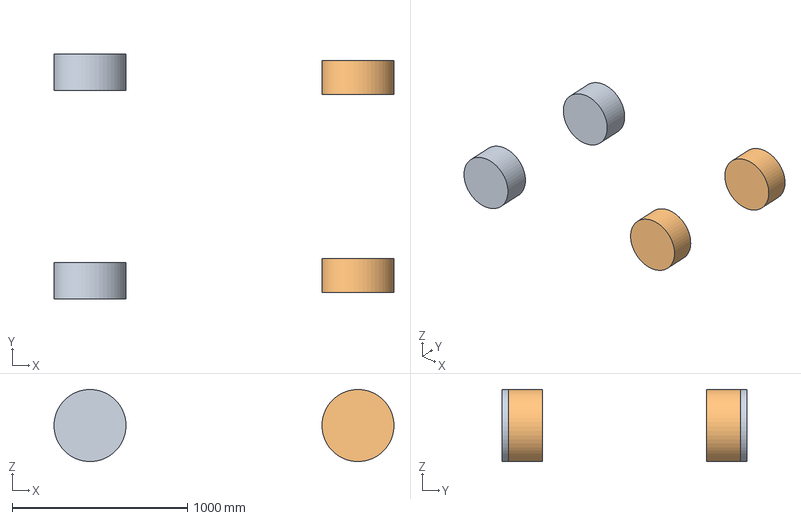
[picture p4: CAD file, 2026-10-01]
team/cad-boxes/out/ref_opony.step
1941.3 x 1400.0 x 411.1 mm
REF_opony_przod
REF_opony_tyl

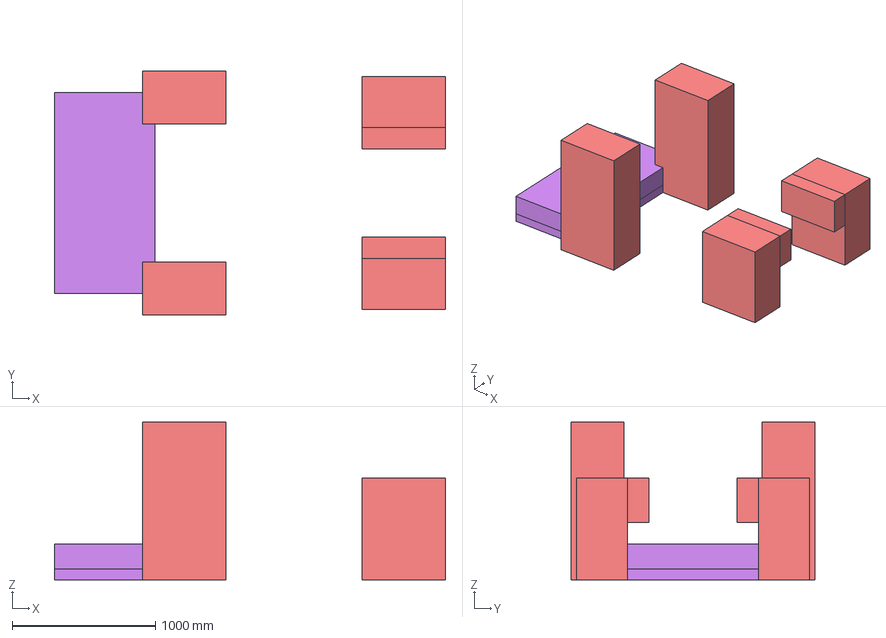
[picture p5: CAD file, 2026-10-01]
team/cad-boxes/out/fs2027_zakazane.step
2726.5 x 1700.0 x 1100.0 mm
KO_2027_T213_kolo_przod
KO_2027_T213_kolo_tyl_do_700
KO_2027_T213_tyl_dodatkowy_150
Q_2027_T214_wariantA_obszar_75wys
Q_2027_T214_wariantB_obszar_250wys

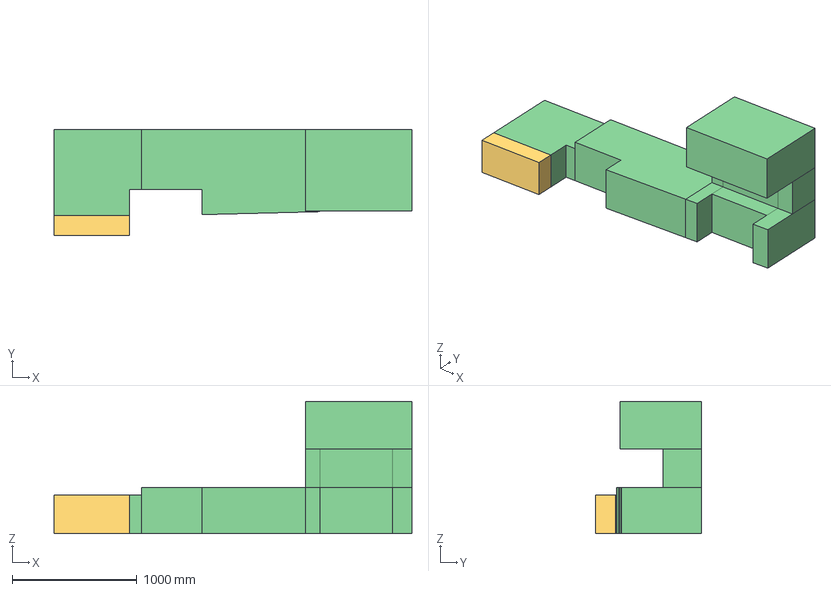
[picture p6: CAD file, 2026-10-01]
team/cad-boxes/out/fs2027_dozwolone_half_yneg.step
2871.5 x 850.0 x 1060.0 mm
OK_2027_przod_ponizej_350
SZARA_2027_przod_outboard_bez_limitu_szer_T822
OK_2027_srodek_ponizej_gory_opon
OK_2027_tyl_nisko_pelna_szer
OK_2027_tyl_pas_gora_opony-700_inboard150
OK_2027_tyl_700-1100_do_zewn_opony

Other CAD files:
team/cad-boxes/ref-kolegi/REF-REGULATIONS-2027.SLDPRT

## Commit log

2026-09-01 Initial FS aero knowledge base
    INDEX, TARGETS, literature claims, team CSV/Excel, Fluent workflow scripts.
    Baseline: RW_iter017. Baseline002 kept as non-current context only.
    [fw-iters-2025-2026.csv, putm-aero-sim-log.xlsx, rw-iters-2025-2026.csv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]
2026-09-01 Freeze RWiter017 balance ~61.6% front and add RW/UT hypotheses
    Team confirmed sheet Cm/Cz balance; ~12 pp to 50/50. Shortlist H1–H5 for Spec approval.
2026-09-01 Lock DRS OUT, fan OUT, 4-element RW candidate, endurance focus
    Update frozen decisions and balance shortlist after lead clarifications.
2026-09-01 Add aero-for-targets research note (H1–H4 guidance)
    Claims-backed advice for max DF, low drag, and ~12 pp rearward balance shift.
2026-09-01 Record Aref half-car ≈0.50 m² for Fluent↔OF comparison
    Team range 0.49–0.51 m² half; full car ≈1.0 m².
2026-09-01 Rewrite team-facing aero docs into plain, readable Polish
    Same numbers, IDs, paths, and claims — clearer headings and jargon explained once for a busy teammate.
2026-09-01 Przepisz TARGETS po ludzku (bez nowych liczb)
    Czytelna karta na rano: RWiter017, Aref 0,50, DRS/fan OUT, kolejność tylne skrzydło → podłoga.
2026-09-01 Add overnight literature note on RW elements, UT yaw, Cl/Cd
    Public papers/theses with citations; no invented numbers. Covers 3vs4-element RW, undertray yaw/balance, published package coefficients.
2026-09-01 Add overnight PL notes on multi-element RW and UT yaw/balance
    Two cited research notes plus morning brief; INDEX pointers updated. No invented Cl/Cd for RWiter017.
2026-09-01 Spięcie nocnego researchu pod cele Spec (bez nowych liczb)
    Kolejka: 3-el. RW najpierw, 4-el. jako porównanie, podłoga pod prostą i zakręt.
2026-09-01 Add AMZ / FaSTTUBe / Running Snail aero intel note
    Public tooling and relative ΔDF only; no invented Cl/Cd. Link from INDEX.
2026-09-02 Przepisz KB aero na czytelny polski (bez nowych liczb)
    Full sentences, segregated coeffs; Spec anchors unchanged (RWiter017, Aref 0.50, DRS/fan OUT, H1→H2).
2026-09-02 Bramka Spec: wiarygodność serii 2D H1 (ΔCl/ΔCd, bez transferu na auto)
2026-09-02 Add sanity-check of CFD#1 2D RW baseline vs literature
    Order-of-magnitude Cl/Cd and McBeath slot check; no TARGETS changes.
2026-09-02 Update 2D RW sanity-check with mesh GCI and A1 Δ
    Agree no full mesh independence; A1 angle trend matches Staniszewski.
2026-09-02 Note A2/A2b Δ vs literature: Cd stall path, Cl in mesh noise
2026-09-02 Add A1b Δ to 2D RW lit sanity-check
2026-09-02 Note A1c Cd plateau vs Staniszewski; still no CAD
2026-09-02 Add H2 undertray balance levers research note
    Ride height, yaw, measurable CFD checklist; no TARGETS changes.
2026-09-02 Add H3 front-wing unload preference note for Spec
    After H1+H2 only; published forces; no TARGETS edits.
2026-09-02 Note medium+ mesh ΔCl worse; y+ too low for gate
2026-09-02 Flag mixed mesh recipes and y+/Cd issues in 2D sanity note
    No TARGETS changes; 3-el vs 4-el absolutes forbidden.
2026-09-02 Przepisz bramkę H1: y+30–300 → mesh study → dopiero kąty/G/O
    Decyzja CAD dopiero po czystym mesh study i Δ wyraźnie powyżej szumu.
2026-09-02 One-pager kampanii Fluent H1 na RWiter017 (2D OF zaparkowane)
    Cele z TARGETS, kill |Cz|/Cx/balans, 3-el. default / 4-el. porównanie.
2026-09-02 Add short H1 Fluent checklist after OpenFOAM 2D stop
    Angles then overlap/gap; stall kills; no foreign Cl/Cd in TARGETS.
2026-09-02 Dodaj protokół 2D OpenFOAM (status ZAPARKOWANE)
    Kolejność: wall-fn → klony mesh → G/O → kąty; link do bramki Spec.
2026-09-02 One-liner: OpenFOAM nie do auta — tylko Fluent; 2D OF zaparkowane
2026-09-02 Dodaj SEASON-DIRECTION.md — podsumowanie i kierunek sezonu
    Baseline RWiter017, kolejka H1→H2→H3, Fluent only, kill z TARGETS.
2026-09-02 Add season geometry/profile candidates from KB papers
    RW 3-el default, UT ~13° Chalmers, FW/whiskers notes; no TARGETS edits.
2026-09-07 Add H2 strakes/yaw/RH deepen and 3vs4 RW team note
    Published numbers only; no TARGETS edits.
2026-09-07 Dodaj MAPA-REPO.md — prosty przewodnik po putm-aero
2026-09-07 WORKFLOW: zasada szum siatki ≪ efekt zmiany geometrii
    Zanim kąty/gap na Fluent; to samo przy powrocie do 2D.
2026-09-30 Źródła | Boxy aero 2027/2026 jako STEP + generator parametryczny
    - team/cad-boxes/gen_boxes.py + params.toml: strefy T 8.2 / T 2.1.3 / T 2.1.4
    jako nazwane bryły (OK_/KO_/Q_/SZARA_/REF_), układ jak w CFD
    - out/: STEP 2027 (full + half y<0), STEP 2026, limits.md, preview.png
    - wymiary z solving.jou (rozstaw osi 1530, R 205.74); rozstaw kół,
    szerokość opon i x HR = placeholdery do podmiany
    - linki w INDEX / MAPA-REPO / fs-rules-2027-t8
    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
    [fs2026_aero_boxes_full.step, fs2027_aero_boxes_full.step, fs2027_aero_boxes_half_yneg.step]
2026-10-01 Źródła | Boxy: osobne pliki dozwolone/zakazane, zapas, wymiary z części kolegi
    - dozwolone (OK) i zakazane (KO/T 2.1.4) w osobnych STEP-ach — w SW nie
    da się ich rozróżnić kolorem; bez płaszczyzn REF 1100x2600
    - params: krawędzie opon i x HR odczytane z REF-REGULATIONS-2027 (zapas
    kolegi cofnięty), margin = 10 mm, width_plane_mode taper/parallel
    - README: porównanie 1:1 z częścią kolegi (pas 85 mm przed oponą za wysoki
    u kolegi; reszta zgodna)
    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
    [REF-REGULATIONS-2027.SLDPRT, fs2026_aero_boxes_full.step, fs2026_dozwolone_full.step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]
